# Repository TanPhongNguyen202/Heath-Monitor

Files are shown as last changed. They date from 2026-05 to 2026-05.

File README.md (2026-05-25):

# Health Monitor v4.0

**ESP32 · FreeRTOS · MAX30105 · MAX30205 · SSD1306 · Firebase**

Hệ thống theo dõi nhịp tim, SpO2 và nhiệt độ cơ thể theo thời gian thực, chạy trên ESP32 với kiến trúc FreeRTOS dual-core. Dữ liệu được lọc nhiễu nhiều tầng, hiển thị sóng Pleth trên OLED 128×64, và đồng bộ lên Firebase Realtime Database mỗi 2 giây.

> ⚠️ **Tuyên bố miễn trách nhiệm:** Thiết bị không phải dụng cụ y tế. Các chỉ số chỉ mang tính tham khảo, không dùng để chẩn đoán bệnh.

---

## Mục lục

- [Tính năng](#tính-năng)
- [Kiến trúc FreeRTOS](#kiến-trúc-freertos)
- [Phần cứng](#phần-cứng)
- [Sơ đồ kết nối](#sơ-đồ-kết-nối)
- [Thư viện](#thư-viện)
- [Cài đặt](#cài-đặt)
- [Cấu trúc dữ liệu Firebase](#cấu-trúc-dữ-liệu-firebase)
- [Tối ưu kỹ thuật](#tối-ưu-kỹ-thuật)
- [Xử lý sự cố](#xử-lý-sự-cố)

---

## Tính năng

- **Dual-core thực sự:** Core 0 xử lý WiFi/Firebase, Core 1 xử lý cảm biến và OLED — không còn giật lag khi gửi dữ liệu.
- **FIFO reading MAX30105:** Drain toàn bộ FIFO mỗi chu kỳ, không bỏ lỡ mẫu giữa các lần gọi như polling thông thường.
- **Circular waveform buffer:** O(1) push và get, không `memmove()`.
- **Lọc tín hiệu nhiều tầng:** Bỏ outlier → IIR → trung bình vòng 8 nhịp.
- **SpO2 chính xác:** Tính tỷ số AC/DC (RMS) của Red và IR, không dùng raw ratio.
- **Phát hiện ngón tay hysteresis:** Ngưỡng ON/OFF tách biệt, tránh trạng thái lật liên tục.
- **Wire mutex:** MAX30105, MAX30205 và SSD1306 dùng chung I2C bus một cách an toàn.

---

## Kiến trúc FreeRTOS

```
Core 0                          Core 1
──────────────────────          ──────────────────────────────────
firebaseTask  (Priority 1)      sensorTask   (Priority 3)
  Đọc healthMutex mỗi 2s          FIFO drain MAX30105
  Firebase.setJSON()               checkForBeat() → HR
  vTaskDelayUntil()                SpO2 AC/DC RMS
                                   MAX30205 mỗi 2s
                                   → write healthMutex
                                   → push irQueue

                                displayTask  (Priority 2)
                                   Drain irQueue → CircBuf
                                   Vẽ sóng IR (không memmove)
                                   Hiển thị HR, SpO2, Temp
                                   vTaskDelayUntil(100ms)

        ┌─────────────────────────────────┐
        │  healthMutex  (HealthData)      │  ← chia sẻ giữa 3 tasks
        │  irQueue      (long, 64 slots)  │  ← sensor → display
        │  wireMutex    (I2C bus)         │  ← sensor + display
        └─────────────────────────────────┘
```

`firebaseTask` bắt buộc ở Core 0 vì WiFi stack của ESP32 chạy trên Core 0. Đặt Firebase ở Core 1 có thể gây deadlock khi chờ WiFi.

---

## Phần cứng

| Linh kiện | Số lượng | Ghi chú |
|---|---|---|
| ESP32 Dev Board | 1 | WROOM, WROVER hoặc tương đương |
| MAX30105 | 1 | Đo nhịp tim + SpO2 |
| MAX30205 | 1 | Đo nhiệt độ cơ thể (I2C) |
| SSD1306 OLED 128×64 | 1 | I2C |
| Dây nối, breadboard | — | |

---

## Sơ đồ kết nối

Tất cả thiết bị dùng chung bus I2C:

| Chân thiết bị | ESP32 |
|---|---|
| VCC (tất cả) | 3.3V |
| GND (tất cả) | GND |
| SDA (tất cả) | GPIO 21 |
| SCL (tất cả) | GPIO 22 |

Địa chỉ I2C mặc định:

| Thiết bị | Địa chỉ |
|---|---|
| SSD1306 OLED | `0x3C` |
| MAX30205 | `0x48` |
| MAX30105 | `0x57` |

> Nếu OLED không hiển thị, dùng sketch quét I2C để xác nhận địa chỉ thực tế.

---

## Thư viện

Cài qua **Library Manager** (Arduino IDE) hoặc khai báo trong `platformio.ini`:

| Thư viện | Nguồn |
|---|---|
| SparkFun MAX30105 | `sparkfun/SparkFun MAX3010x Pulse and Proximity Sensor Library` |
| Protocentral MAX30205 | `protocentral/Protocentral MAX30205` |
| Adafruit SSD1306 | `adafruit/Adafruit SSD1306` |
| Adafruit GFX | `adafruit/Adafruit GFX Library` |
| Firebase ESP32 Client | `mobizt/Firebase ESP32 Client` |
| WiFiManager | `tzapu/WiFiManager` |

**`platformio.ini` mẫu:**

```ini
[env:esp32dev]
platform  = espressif32
board     = esp32dev
framework = arduino
monitor_speed = 115200
lib_deps =
    sparkfun/SparkFun MAX30105 Pulse Oximeter and Heart Rate Sensor@^1.1.3
    protocentral/Protocentral MAX30205@^1.0.0
    adafruit/Adafruit SSD1306@^2.5.7
    adafruit/Adafruit GFX Library@^1.11.5
    mobizt/Firebase ESP32 Client@^4.3.9
    tzapu/WiFiManager@^2.0.16-rc2
```

---

## Cài đặt

### 1. Cấu hình Firebase

Sửa 2 hằng số trong file `.ino`:

```cpp
#define DATABASE_URL    "https://your-project-default-rtdb.firebaseio.com/"
#define DATABASE_SECRET "your_database_secret"
```

### 2. Nạp code

Nạp code lên ESP32 qua Arduino IDE hoặc PlatformIO.

### 3. Kết nối WiFi lần đầu

ESP32 tạo Access Point tên `ESP32_HealthMonitor`. Kết nối vào AP đó bằng điện thoại hoặc laptop, chọn mạng WiFi và nhập mật khẩu. Thông tin WiFi được lưu lại, các lần sau tự kết nối.

### 4. Kiểm tra

Đặt ngón tay lên MAX30105. OLED hiển thị sóng Pleth và các chỉ số. Mở Serial Monitor (115200 baud) để theo dõi log từng task.

---

## Cấu trúc dữ liệu Firebase

Dữ liệu ghi vào đường dẫn `/Health`, cập nhật mỗi 2 giây khi có ngón tay và đủ dữ liệu:

```json
{
  "HR":   78.0,
  "SpO2": 97.2,
  "Temp": 36.8,
  "ts":   1698765432
}
```

| Trường | Kiểu | Mô tả |
|---|---|---|
| `HR` | float | Trung bình 8 nhịp gần nhất (BPM) |
| `SpO2` | float | Độ bão hòa oxy máu, 80–100% |
| `Temp` | float | Nhiệt độ cơ thể (°C) |
| `ts` | int | Giây tính từ khi ESP32 khởi động (`millis()/1000`) |

Nếu ngón tay chưa đặt hoặc HR/SpO2 chưa ổn định (= 0), dữ liệu không được gửi.

---

## Tối ưu kỹ thuật

### FIFO reading MAX30105

Thay vì `getIR()` / `getRed()` (polling, bỏ mẫu), code drain toàn bộ FIFO mỗi chu kỳ:

```cpp
particleSensor.check();                  // nạp FIFO vào internal buffer
while (particleSensor.available()) {
    long ir  = particleSensor.getFIFOIR();
    long red = particleSensor.getFIFORed();
    particleSensor.nextSample();         // advance pointer
    // xử lý ir, red...
}
```

MAX30105 cấu hình 100 SPS, sample average 4 → ~25 entries/giây vào FIFO 32 slots. `sensorTask` chạy 200Hz (`vTaskDelay(5ms)`) — không bao giờ overflow.

### Circular waveform buffer

```cpp
// Push O(1) — không copy
buf[head] = pt;
head = (head + 1) % SCREEN_WIDTH;

// Get O(1) — index vòng
int16_t get(int i) { return buf[(head + i) % SCREEN_WIDTH]; }
```

So sánh với `memmove()` cũ: 10 FPS × 127 × 2 bytes = ~2.5 KB/s copy không cần thiết trên Core 1.

### Lọc nhịp tim

```
rawHR → bỏ outlier (|Δ| > 20 BPM) → IIR α=0.25 → lưu history
beatAvg = trung bình 8 nhịp gần nhất → gửi Firebase
```

### Tính SpO2

```
DC  = mean(buffer 100 mẫu)
AC  = RMS(buffer - DC)
R   = (AC_red / DC_red) / (AC_ir / DC_ir)
SpO2 = 104 - 17×R  →  IIR α=0.10
```

---

## Xử lý sự cố

| Hiện tượng | Nguyên nhân / Cách xử lý |
|---|---|
| OLED trống | Sai địa chỉ I2C — dùng sketch quét I2C kiểm tra |
| Không vào WiFi | Kết nối vào AP `ESP32_HealthMonitor`, cấu hình lại |
| HR/SpO2 = 0 mãi | Chưa đặt ngón tay đúng cách hoặc LED brightness quá thấp |
| MAX30205 không đọc được | Code tự retry 5 lần — kiểm tra hàn SDA/SCL |
| Firebase lỗi auth | Sai `DATABASE_SECRET` hoặc `DATABASE_URL` |
| ESP32 reset liên tục | Stack task quá nhỏ — tăng `*_STACK` trong code |
| Sóng OLED không mượt | Tăng `IR_QUEUE_LEN` hoặc giảm tần suất ghi Serial |
| Nhiệt độ lệch | Điều chỉnh `TEMP_OFFSET` (mặc định `0.3°C`) |

---

## Giấy phép

Mã nguồn mở, miễn phí cho mục đích học tập và nghiên cứu cá nhân.

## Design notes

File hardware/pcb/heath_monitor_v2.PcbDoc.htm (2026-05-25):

Reporting Options

# File in Previous Format

Date | : | 5/25/2026
Time | : | 11:47:02 PM
Filename | : | C:\Users\Admin\Documents\Heath\Heath-Monitor\hardware\pcb\heath_monitor_v2.PcbDoc

Version | Warning

This file was generated by an earlier version of the software

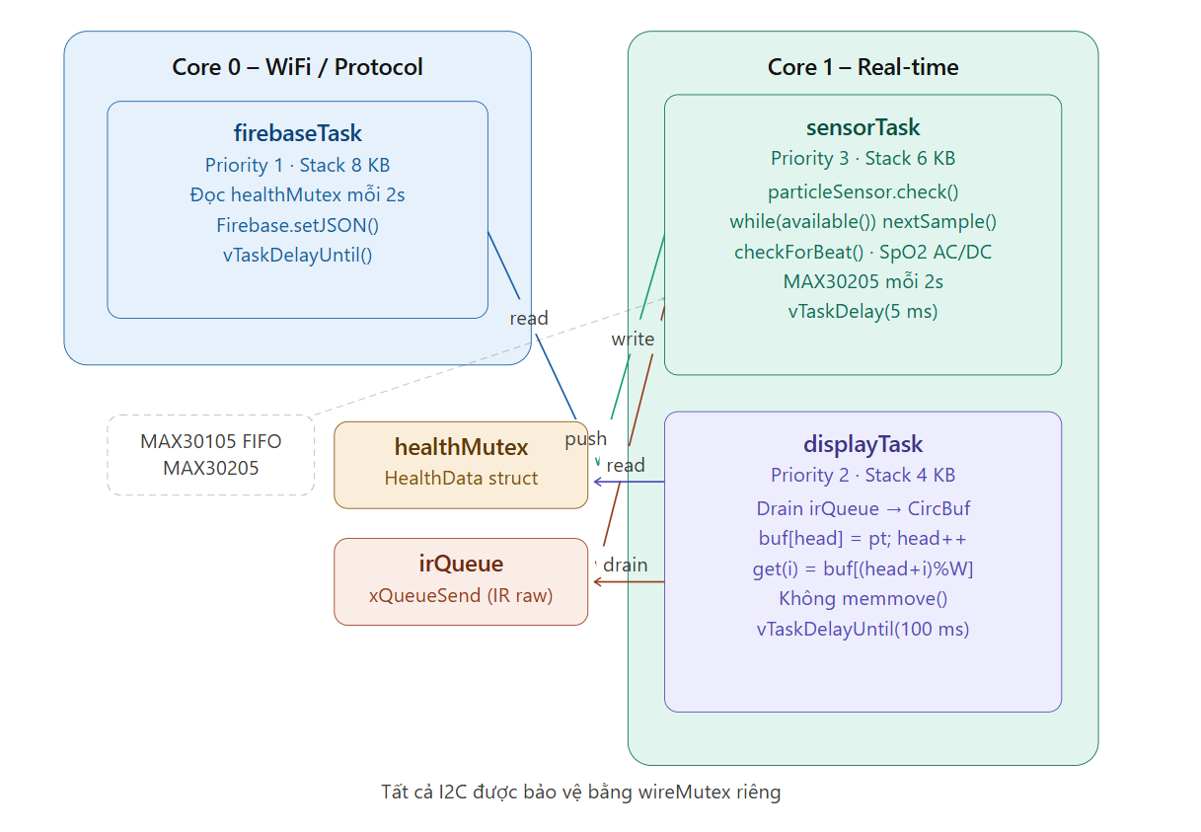
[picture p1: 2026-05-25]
image.png

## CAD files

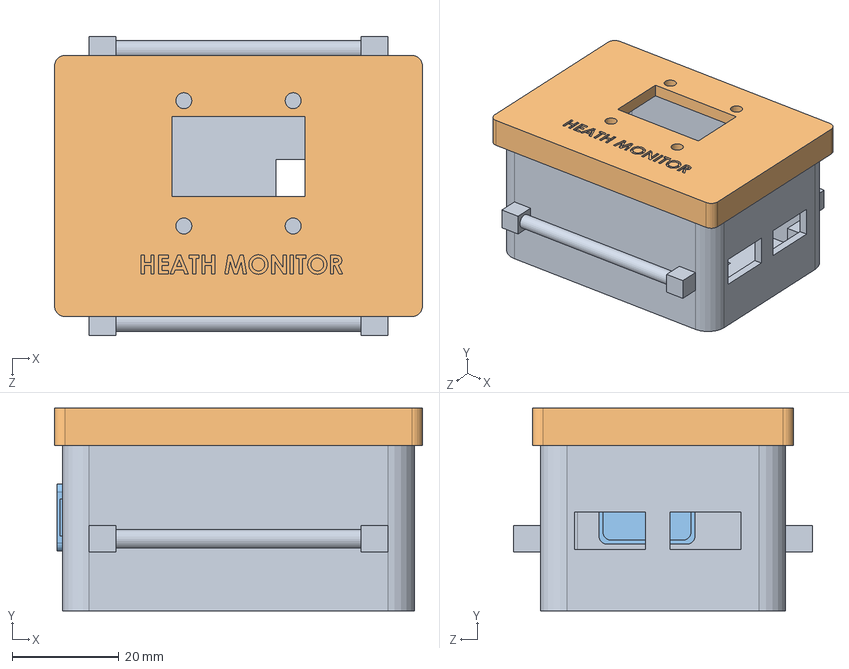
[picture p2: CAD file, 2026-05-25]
hardware/3d/heathmoniter.SLDASM
69.0 x 38.0 x 56.0 mm
dongho
nap
napday

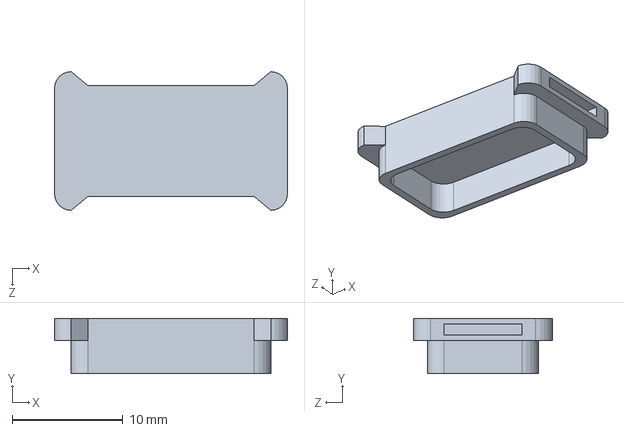
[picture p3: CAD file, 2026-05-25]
hardware/3d/napday.SLDPRT
21.0 x 5.00 x 12.5 mm

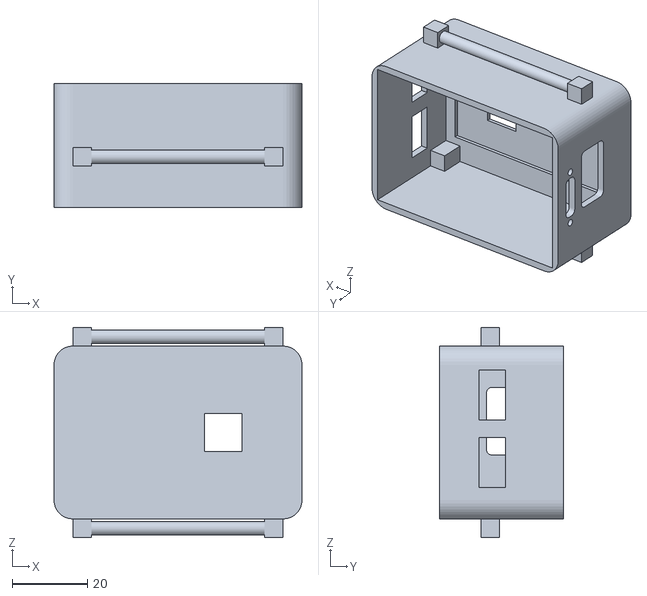
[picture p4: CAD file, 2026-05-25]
hardware/3d/than2.STL
66.0 x 33.0 x 56.0

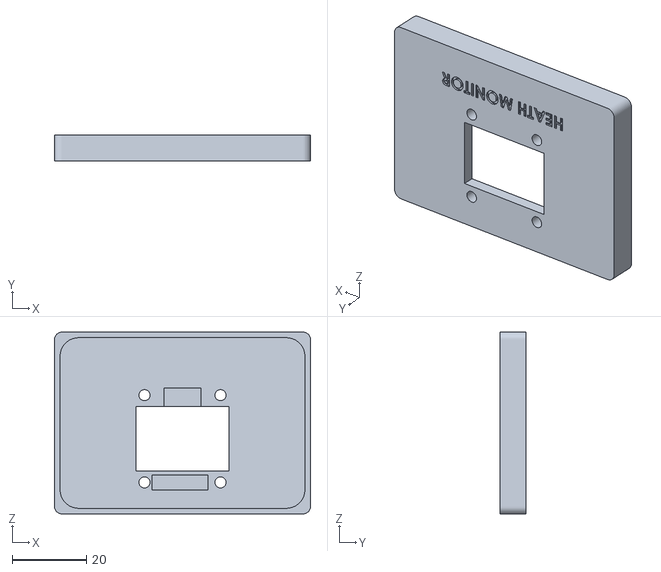
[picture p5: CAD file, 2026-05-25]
hardware/3d/mattrenv2.STL
69.0 x 7.00 x 49.0

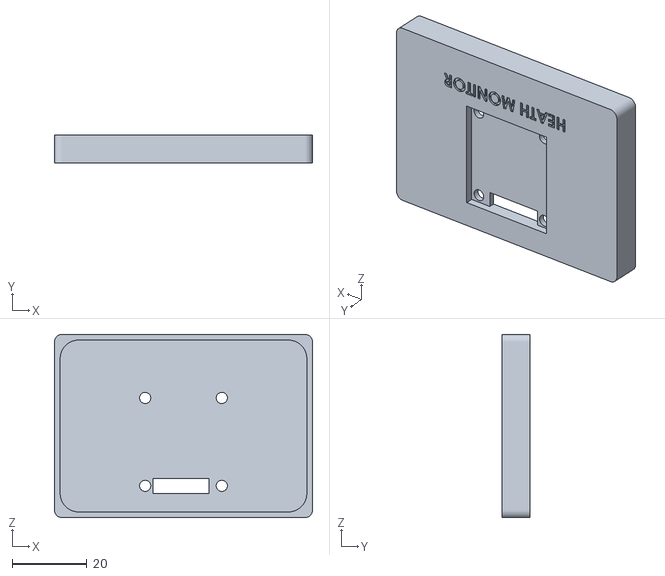
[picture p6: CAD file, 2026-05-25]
hardware/3d/mattren.STL
69.0 x 7.50 x 49.0

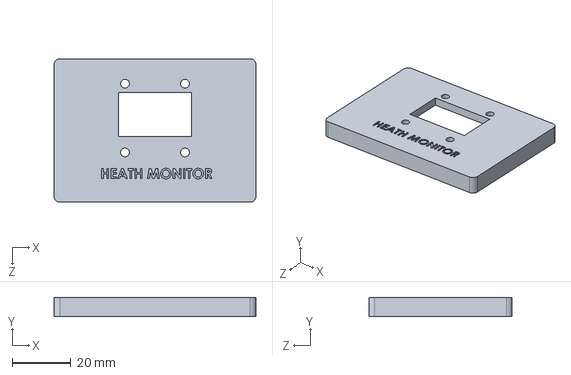
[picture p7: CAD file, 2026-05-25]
hardware/3d/nap.SLDPRT
69.0 x 6.50 x 49.0 mm

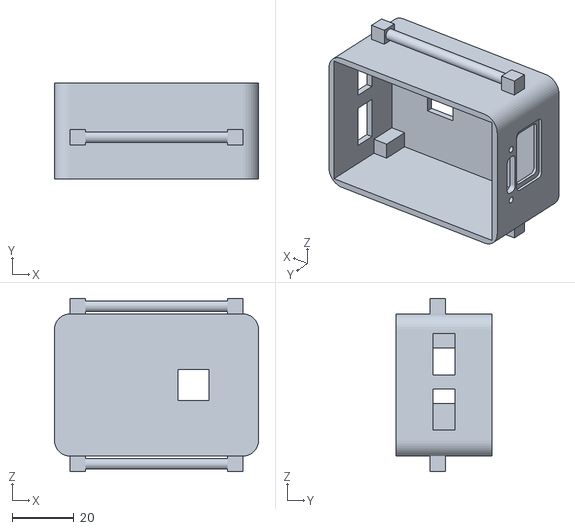
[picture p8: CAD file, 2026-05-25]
hardware/3d/than.STL
66.0 x 31.0 x 56.0

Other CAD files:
hardware/3d/napdayv2.STL
hardware/3d/dongho.SLDPRT
hardware/3d/napv2.STL
hardware/3d/dongho.STL
hardware/3d/nap.STL
hardware/3d/napday.STL

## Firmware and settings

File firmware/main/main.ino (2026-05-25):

/**
 * ============================================================
 *  Health Monitor v4.0 – FreeRTOS Dual-Core
 *  ESP32 + MAX30105 + MAX30205 + SSD1306 + Firebase
 * ============================================================
 *
 *  [1] FreeRTOS dual-core
 *      Core 0: firebaseTask (P1) – WiFi/Firebase nằm đây vì WiFi stack cũng ở Core 0
 *      Core 1: sensorTask (P3) + displayTask (P2) – real-time, không bị WiFi tranh CPU
 *
 *  [2] Circular waveform buffer
 *      push() = O(1), get(i) = O(1)
 *      Không còn memmove() (O(N) mỗi frame = ~12 KB copy/frame @ 10 FPS)
 *
 *  [3] FIFO reading MAX30105
 *      particleSensor.check() → available() → getFIFOIR/Red() → nextSample()
 *      Thay vì gọi getIR()/getRed() mỗi loop (polling bỏ lỡ mẫu giữa các call)
 *
 *  [4] Wire mutex
 *      MAX30105, MAX30205, SSD1306 đều dùng I2C.
 *      wireMutex bảo đảm chỉ 1 task dùng bus tại một thời điểm.
 *
 *  [5] HealthData chia sẻ qua healthMutex (SemaphoreHandle_t)
 *  [6] IR samples truyền từ sensorTask → displayTask qua irQueue
 * ============================================================
 */

#include <Wire.h>
#include "MAX30105.h"
#include "heartRate.h"               // checkForBeat() chính thức
#include "Protocentral_MAX30205.h"
#include <WiFi.h>
#include <FirebaseESP32.h>
#include <Adafruit_GFX.h>
#include <Adafruit_SSD1306.h>
#include <WiFiManager.h>
#include <freertos/FreeRTOS.h>
#include <freertos/task.h>
#include <freertos/semphr.h>
#include <freertos/queue.h>
#include <algorithm>
#include <cmath>

// ============================================================
//  CẤU HÌNH
// ============================================================

#define DATABASE_URL    "https://healthmonitor-a6b4e-default-rtdb.firebaseio.com/"
#define DATABASE_SECRET "7HKiz6i3KRUnQ9b69ldM83uu4cHVvqCQwLF1OrDP"
#define FIREBASE_PATH   "/Health"

#define SCREEN_WIDTH  128
#define SCREEN_HEIGHT  64
#define OLED_RESET     -1

// Hysteresis ngón tay (MAX30105 trả ~50k-150k khi có ngón)
#define FINGER_ON_THRESHOLD  50000L
#define FINGER_OFF_THRESHOLD 30000L

// HR
#define HR_RATES_SIZE    8
#define HR_HISTORY_SIZE  30
#define HR_MIN           30.0f
#define HR_MAX           200.0f
#define HR_OUTLIER_THR   20.0f
#define IIR_ALPHA_HR     0.25f
#define IIR_ALPHA_SPO2   0.10f

// Nhiệt độ
#define TEMP_OFFSET   0.3f
#define TEMP_MIN      34.0f
#define TEMP_MAX      42.0f
#define TEMP_INTERVAL_MS 2000

// SpO2
#define SPO2_BUF_SIZE    100
#define SPO2_MIN_SAMPLES  40

// Task
#define SENSOR_STACK    6144
#define DISPLAY_STACK   4096
#define FIREBASE_STACK  8192    // Firebase + WiFi cần stack lớn

// Queue IR: đủ chứa 1 giây mẫu (100 SPS / 4 avg = 25 entries/s)
// displayTask chạy 10Hz nên drain 2-3 entry/lần là bình thường
#define IR_QUEUE_LEN  64

// Firebase interval
#define FIREBASE_INTERVAL_MS 2000

// ============================================================
//  SHARED DATA – bảo vệ bởi healthMutex
// ============================================================

struct HealthData {
  float hr       = 0.0f;
  float beatAvg  = 0.0f;
  float spO2     = 0.0f;
  float tempC    = 0.0f;
  bool  fingerOn = false;
  bool  ready    = false;   // đủ dữ liệu HR + SpO2
};

SemaphoreHandle_t healthMutex;   // Bảo vệ sharedHealth
HealthData        sharedHealth;

// Queue IR samples từ sensorTask → displayTask
QueueHandle_t irQueue;

// Mutex I2C Wire (dùng chung bởi sensorTask + displayTask)
SemaphoreHandle_t wireMutex;

// ============================================================
//  HARDWARE OBJECTS
// ============================================================

FirebaseData   fbData;
FirebaseAuth   fbAuth;
FirebaseConfig fbConfig;

Adafruit_SSD1306 display(SCREEN_WIDTH, SCREEN_HEIGHT, &Wire, OLED_RESET);
MAX30105  particleSensor;
MAX30205  tempSensor;
bool      tempSensorOK = false;

// ============================================================
//  [2] CIRCULAR WAVEFORM BUFFER – O(1) push & get, không memmove
// ============================================================

struct CircularWaveBuffer {
  int16_t buf[SCREEN_WIDTH];
  int     head = 0;           // Điểm sẽ ghi tiếp theo
  long    irMin = FINGER_ON_THRESHOLD;
  long    irMax = FINGER_ON_THRESHOLD + 10000L;

  // Gọi sau khi finger removed
  void reset() {
    int mid = (SCREEN_HEIGHT - 18) / 2;
    for (int i = 0; i < SCREEN_WIDTH; i++) buf[i] = mid;
    head  = 0;
    irMin = FINGER_ON_THRESHOLD;
    irMax = FINGER_ON_THRESHOLD + 10000L;
  }

  // O(1): ghi điểm mới, tự scale
  void push(long irValue) {
    // Auto-scale với decay chậm (tránh drift khi tín hiệu thay đổi dần)
    if (irValue > irMax)     irMax = irValue;
    else                     irMax = (long)(irMax * 0.9995f + irValue * 0.0005f);
    if (irValue < irMin)     irMin = irValue;
    else                     irMin = (long)(irMin * 0.9995f + irValue * 0.0005f);
    if (irMax - irMin < 500) irMax = irMin + 500;   // tránh chia 0

    const int waveH = SCREEN_HEIGHT - 18;
    int pt = (int)map(irValue, irMin, irMax, waveH - 2, 2);
    pt = constrain(pt, 0, waveH - 1);

    buf[head] = (int16_t)pt;
    head = (head + 1) % SCREEN_WIDTH;  // wrap around
  }

  // O(1): lấy điểm thứ i (i=0 cũ nhất, i=W-1 mới nhất)
  int16_t get(int i) const {
    return buf[(head + i) % SCREEN_WIDTH];
  }
};

CircularWaveBuffer waveBuffer;

// ============================================================
//  SPO2 – tỷ số AC/DC (RMS)
// ============================================================

float calculateSpO2(long* red, long* ir, int len) {
  if (len < SPO2_MIN_SAMPLES) return 0.0f;

  double dcRed = 0, dcIR = 0;
  for (int i = 0; i < len; i++) { dcRed += red[i]; dcIR += ir[i]; }
  dcRed /= len;
  dcIR  /= len;

  if (dcRed < 5000 || dcIR < 5000) return 0.0f;

  double acRed = 0, acIR = 0;
  for (int i = 0; i < len; i++) {
    double dr = red[i] - dcRed;
    double di = ir[i]  - dcIR;
    acRed += dr * dr;
    acIR  += di * di;
  }
  acRed = sqrt(acRed / len);
  acIR  = sqrt(acIR  / len);

  if (acIR < 1.0) return 0.0f;

  double R    = (acRed / dcRed) / (acIR / dcIR);
  double spo2 = 104.0 - 17.0 * R;
  return (float)constrain(spo2, 80.0, 100.0);
}

inline float iirFilter(float nv, float pv, float a) {
  return a * nv + (1.0f - a) * pv;
}

// ============================================================
//  WIFI & FIREBASE
// ============================================================

void setupWiFi() {
  WiFiManager wm;
  wm.setConnectTimeout(30);
  wm.setConfigPortalTimeout(120);
  if (!wm.autoConnect("ESP32_HealthMonitor")) {
    Serial.println("WiFi failed, restarting...");
    delay(2000);
    ESP.restart();
  }
  Serial.printf("[WiFi] %s\n", WiFi.localIP().toString().c_str());
}

void initFirebase() {
  fbConfig.database_url               = DATABASE_URL;
  fbConfig.signer.tokens.legacy_token = DATABASE_SECRET;
  Firebase.begin(&fbConfig, &fbAuth);
  Firebase.reconnectWiFi(true);
  Firebase.setDoubleDigits(1);
}

// ============================================================
//  DISPLAY HELPERS (gọi trong wireMutex)
// ============================================================

void showMessage(const char* l1, const char* l2 = nullptr) {
  display.clearDisplay();
  display.setTextSize(1);
  display.setTextColor(SSD1306_WHITE);
  display.setCursor(8, 18); display.print(l1);
  if (l2) { display.setCursor(8, 32); display.print(l2); }
  display.display();
}

// ============================================================
//  [1] SENSOR TASK – Core 1, Priority 3
//  [3] Dùng FIFO reading, không polling
// ============================================================

void sensorTask(void* pv) {
  // --- State cục bộ của task ---
  float  hrRates[HR_RATES_SIZE]     = {0};
  float  hrHistory[HR_HISTORY_SIZE] = {0};
  int    hrRateSpot = 0, hrHistIdx = 0, hrHistCount = 0;
  float  hrIIR = 0.0f, spo2IIR = 0.0f;
  long   lastBeatTime = 0;

  long   redBuf[SPO2_BUF_SIZE];
  long   irBuf[SPO2_BUF_SIZE];
  int    spo2Idx = 0;
  bool   spo2Full = false;

  bool   fingerOn = false;
  unsigned long lastTempMs = 0;
  HealthData local;

  while (true) {
    // ============================================================
    //  [3] FIFO READ – đọc tất cả samples tích lũy kể từ lần trước
    //  Thay vì getIR()/getRed() chỉ lấy 1 giá trị và bỏ các mẫu giữa
    // ============================================================
    byte newSamples = particleSensor.check();   // đọc FIFO vào buffer nội

    // Xử lý từng sample trong internal buffer
    while (particleSensor.available()) {
      long ir  = particleSensor.getFIFOIR();
      long red = particleSensor.getFIFORed();
      particleSensor.nextSample();    // advance FIFO pointer

      unsigned long now = millis();

      // ---- Hysteresis ngón tay ----
      bool prevFinger = fingerOn;
      if (!fingerOn && ir > FINGER_ON_THRESHOLD)  fingerOn = true;
      if ( fingerOn && ir < FINGER_OFF_THRESHOLD) fingerOn = false;

      if (prevFinger && !fingerOn) {
        // Vừa rút ngón – reset toàn bộ
        hrRateSpot = hrHistIdx = hrHistCount = 0;
        hrIIR = spo2IIR = 0.0f;
        spo2Idx = 0; spo2Full = false;
        lastBeatTime = 0;
        memset(hrRates,   0, sizeof(hrRates));
        memset(hrHistory, 0, sizeof(hrHistory));
        local = HealthData();
        // Cập nhật shared
        if (xSemaphoreTake(healthMutex, pdMS_TO_TICKS(5)) == pdTRUE) {
          sharedHealth = local;
          xSemaphoreGive(healthMutex);
        }
        // Báo displayTask biết không có ngón
        long dummy = 0;
        xQueueSend(irQueue, &dummy, 0);
        continue;
      }

      if (!fingerOn) {
        long dummy = 0;
        xQueueSend(irQueue, &dummy, 0);
        continue;
      }

      // ---- Phát hiện nhịp tim ----
      if (checkForBeat(ir)) {
        long delta = now - lastBeatTime;
        if (lastBeatTime > 0 && delta > 200 && delta < 2000) {  // 30-300 BPM
          float rawHR = 60000.0f / (float)delta;

          if (rawHR >= HR_MIN && rawHR <= HR_MAX) {
            // Bỏ outlier
            float prevHR = (hrHistCount > 0)
              ? hrHistory[(hrHistIdx - 1 + HR_HISTORY_SIZE) % HR_HISTORY_SIZE]
              : rawHR;
            float useHR = (fabsf(rawHR - prevHR) > HR_OUTLIER_THR) ? prevHR : rawHR;

            // IIR
            hrIIR = (hrIIR < 1.0f) ? useHR : iirFilter(useHR, hrIIR, IIR_ALPHA_HR);

            // Lịch sử vòng
            hrHistory[hrHistIdx] = hrIIR;
            hrHistIdx = (hrHistIdx + 1) % HR_HISTORY_SIZE;
            if (hrHistCount < HR_HISTORY_SIZE) hrHistCount++;

            // beatAvg = trung bình HR_RATES_SIZE nhịp gần nhất
            hrRates[hrRateSpot] = (byte)constrain((int)hrIIR, 0, 255);
            hrRateSpot = (hrRateSpot + 1) % HR_RATES_SIZE;
            float avg = 0;
            for (int i = 0; i < HR_RATES_SIZE; i++) avg += hrRates[i];
            avg /= HR_RATES_SIZE;

            local.hr      = hrIIR;
            local.beatAvg = avg;
            Serial.printf("[HR] raw=%.0f iir=%.1f avg=%.1f\n", rawHR, hrIIR, avg);
          }
        }
        lastBeatTime = now;
      }

      // ---- Buffer SpO2 ----
      redBuf[spo2Idx] = red;
      irBuf[spo2Idx]  = ir;
      spo2Idx = (spo2Idx + 1) % SPO2_BUF_SIZE;
      if (spo2Idx == 0) spo2Full = true;

      int sampLen = spo2Full ? SPO2_BUF_SIZE : spo2Idx;
      if (sampLen >= SPO2_MIN_SAMPLES) {
        float raw = calculateSpO2(redBuf, irBuf, sampLen);
        if (raw >= 80.0f) {
          spo2IIR = (spo2IIR < 1.0f) ? raw : iirFilter(raw, spo2IIR, IIR_ALPHA_SPO2);
          local.spO2 = spo2IIR;
        }
      }

      local.fingerOn = true;
      local.ready    = (local.beatAvg > 0 && local.spO2 > 0);

      // Đẩy IR vào queue cho displayTask vẽ sóng
      // xQueueSend với timeout=0: bỏ qua nếu queue đầy (display lag thì cũng không crash)
      xQueueSend(irQueue, &ir, 0);
    }

    // ---- Đọc nhiệt độ (ngoài FIFO loop, mỗi 2s) ----
    unsigned long now2 = millis();
    if (tempSensorOK && now2 - lastTempMs > TEMP_INTERVAL_MS) {
      lastTempMs = now2;

      // Lấy wireMutex trước khi dùng I2C
      if (xSemaphoreTake(wireMutex, pdMS_TO_TICKS(10)) == pdTRUE) {
        float t = tempSensor.getTemperature() + TEMP_OFFSET;
        xSemaphoreGive(wireMutex);
        if (t >= TEMP_MIN && t <= TEMP_MAX) local.tempC = t;
      }
    }

    // ---- Cập nhật shared health ----
    if (xSemaphoreTake(healthMutex, pdMS_TO_TICKS(5)) == pdTRUE) {
      sharedHealth = local;
      xSemaphoreGive(healthMutex);
    }

    // Yield 5ms – FIFO 100SPS / avg4 = 25 entries/s, task chạy 200Hz là dư
    vTaskDelay(pdMS_TO_TICKS(5));
  }
}

// ============================================================
//  [1] DISPLAY TASK – Core 1, Priority 2
// ============================================================

void displayTask(void* pv) {
  const TickType_t period  = pdMS_TO_TICKS(100);   // 10 FPS
  TickType_t       lastWake = xTaskGetTickCount();

  while (true) {
    // Đọc shared health
    HealthData h;
    if (xSemaphoreTake(healthMutex, pdMS_TO_TICKS(10)) == pdTRUE) {
      h = sharedHealth;
      xSemaphoreGive(healthMutex);
    }

    if (!h.fingerOn) {
      // Không có ngón: xóa buffer, hiện thông báo
      waveBuffer.reset();
      if (xSemaphoreTake(wireMutex, pdMS_TO_TICKS(20)) == pdTRUE) {
        showMessage("Place your finger", "   on sensor");
        xSemaphoreGive(wireMutex);
      }
      // Drain queue để không tích lũy
      long dummy;
      while (xQueueReceive(irQueue, &dummy, 0) == pdTRUE) {}

    } else {
      // Drain toàn bộ IR queue → push vào circular buffer
      long irVal;
      while (xQueueReceive(irQueue, &irVal, 0) == pdTRUE) {
        if (irVal > 0) waveBuffer.push(irVal);
      }

      // Vẽ lên OLED (cần wireMutex vì dùng I2C)
      if (xSemaphoreTake(wireMutex, pdMS_TO_TICKS(20)) == pdTRUE) {
        const int waveH = SCREEN_HEIGHT - 18;

        // Xóa vùng sóng
        display.fillRect(0, 0, SCREEN_WIDTH, waveH, SSD1306_BLACK);

        // [2] Vẽ từ circular buffer – không memmove
        for (int i = 1; i < SCREEN_WIDTH; i++) {
          display.drawLine(
            i - 1, waveBuffer.get(i - 1),
            i,     waveBuffer.get(i),
            SSD1306_WHITE
          );
        }

        // Thanh thông tin
        display.fillRect(0, waveH, SCREEN_WIDTH, SCREEN_HEIGHT - waveH, SSD1306_BLACK);
        display.drawFastHLine(0, waveH, SCREEN_WIDTH, SSD1306_WHITE);
        display.setTextSize(1);
        display.setTextColor(SSD1306_WHITE);

        char buf[24];
        if (h.beatAvg > 0 && h.spO2 > 0) {
          snprintf(buf, sizeof(buf), "HR:%3d SpO2:%2d%%", (int)h.beatAvg, (int)h.spO2);
        } else {
          snprintf(buf, sizeof(buf), "HR:--- SpO2:--%% ");
        }
        display.setCursor(0, waveH + 2);  display.print(buf);

        if (h.tempC > 0) {
          snprintf(buf, sizeof(buf), "Temp: %.1fC", h.tempC);
        } else {
          snprintf(buf, sizeof(buf), "Temp: --.--C");
        }
        display.setCursor(0, waveH + 11); display.print(buf);

        display.display();
        xSemaphoreGive(wireMutex);
      }
    }

    vTaskDelayUntil(&lastWake, period);
  }
}

// ============================================================
//  [1] FIREBASE TASK – Core 0, Priority 1
//  Ở Core 0 vì WiFi stack của ESP32 chạy trên Core 0
// ============================================================

void firebaseTask(void* pv) {
  const TickType_t period  = pdMS_TO_TICKS(FIREBASE_INTERVAL_MS);
  TickType_t       lastWake = xTaskGetTickCount();

  while (true) {
    HealthData h;
    if (xSemaphoreTake(healthMutex, pdMS_TO_TICKS(10)) == pdTRUE) {
      h = sharedHealth;
      xSemaphoreGive(healthMutex);
    }

    if (h.ready && h.fingerOn) {
      FirebaseJson json;
      json.set("HR",   (double)h.beatAvg);
      json.set("SpO2", (double)h.spO2);
      json.set("Temp", (double)h.tempC);
      json.set("ts",   (long)(millis() / 1000));

      if (Firebase.setJSON(fbData, FIREBASE_PATH, json)) {
        Serial.printf("[FB] HR:%.0f SpO2:%.1f Temp:%.1f\n",
                      h.beatAvg, h.spO2, h.tempC);
      } else {
        Serial.println("[FB] Err: " + fbData.errorReason());
      }
    }

    vTaskDelayUntil(&lastWake, period);
  }
}

// ============================================================
//  SETUP
// ============================================================

void setup() {
  Serial.begin(115200);
  Serial.println("\n=== Health Monitor v4.0 (FreeRTOS) ===");

  Wire.begin();

  // OLED
  if (!display.begin(SSD1306_SWITCHCAPVCC, 0x3C)) {
    Serial.println("OLED FAILED"); while (1);
  }
  waveBuffer.reset();
  showMessage("Connecting...");

  setupWiFi();
  initFirebase();

  showMessage("Init sensors...");

  // MAX30105 – cấu hình 18-bit, 100 SPS, avg=4
  if (!particleSensor.begin(Wire, I2C_SPEED_FAST)) {
    showMessage("MAX30105 error!"); while (1);
  }
  particleSensor.setup(
    0x1F,   // LED brightness ~6.4 mA
    4,      // sample average (giảm nhiễu)
    2,      // mode: Red + IR (bắt buộc cho SpO2)
    100,    // sample rate: 100 SPS
    411,    // pulse width: 411µs = 18-bit ADC
    4096    // ADC range: 4096 nA full scale
  );
  particleSensor.setPulseAmplitudeRed(0x1F);
  particleSensor.setPulseAmplitudeIR(0x1F);
  particleSensor.setPulseAmplitudeGreen(0);

  // MAX30205
  for (int i = 5; i > 0; i--) {
    if (tempSensor.scanAvailableSensors()) {
      tempSensor.begin();
      tempSensorOK = true;
      Serial.println("[TEMP] MAX30205 OK");
      break;
    }
    Serial.printf("[TEMP] Retry %d...\n", 6 - i);
    delay(2000);
  }
  if (!tempSensorOK) Serial.println("[TEMP] Not found – disabled");

  // FreeRTOS primitives
  healthMutex = xSemaphoreCreateMutex();
  wireMutex   = xSemaphoreCreateMutex();
  irQueue     = xQueueCreate(IR_QUEUE_LEN, sizeof(long));

  if (!healthMutex || !wireMutex || !irQueue) {
    Serial.println("RTOS init FAILED"); while (1);
  }

  // Tạo tasks – pinned to core
  //                         name        stack           param prio handle core
  xTaskCreatePinnedToCore(sensorTask,  "Sensor",  SENSOR_STACK,  NULL, 3, NULL, 1);
  xTaskCreatePinnedToCore(displayTask, "Display", DISPLAY_STACK, NULL, 2, NULL, 1);
  xTaskCreatePinnedToCore(firebaseTask,"Firebase",FIREBASE_STACK,NULL, 1, NULL, 0);

  Serial.println("[RTOS] Tasks started");

  // Xóa Arduino loop task – không dùng nữa
  vTaskDelete(NULL);
}

// ============================================================
//  LOOP – không dùng, đã xóa ở setup()
// ============================================================
void loop() {}

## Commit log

2026-05-25 Tối ưu code:
2026-05-25 refactor: nâng cấp xử lý SpO2 & nhịp tim – chính xác, ổn định, hiệu quả - SpO2 chính xác hơn: dùng tỷ số AC/DC (RMS) của kênh Red và IR - Phát hiện nhịp: dùng checkForBeat() từ thư viện heartRate.h -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
    [Max30102_40k.SchLib, Max30205.PcbLib, Max30205.SchLib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]
2026-05-25 refactor: FreeRTOS dual-core, tối ưu bộ đệm và đồng bộ I2C [1] FreeRTOS phân chia nhân: - Core 0: firebaseTask (ưu tiên P1) – WiFi/Firebase (WiFi stack cũng ở core 0) - Core 1: sensorTask (P3) + disp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
2026-05-25 docs: cập nhật README và requirements cho hệ thống dual-core FreeRTOS - Mô tả kiến trúc: core0 (WiFi/Firebase), core1 (cảm biến + hiển thị) - Thêm hướng dẫn cấu hình MAX30105, MAX30205, SSD1306, I2C 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
2026-05-25 Update Pcb v2
    [heath_monitor_v2.PcbDoc]
